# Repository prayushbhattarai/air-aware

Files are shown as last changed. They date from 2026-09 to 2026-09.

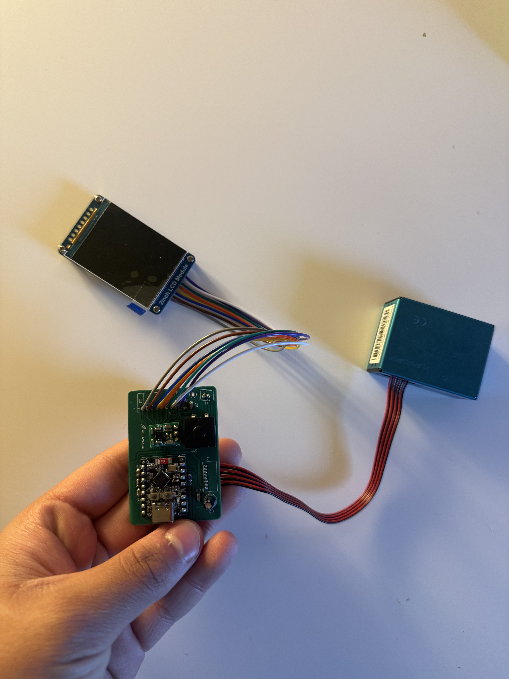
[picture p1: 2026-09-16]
media/assembled/assembled-pcb-whole.jpeg

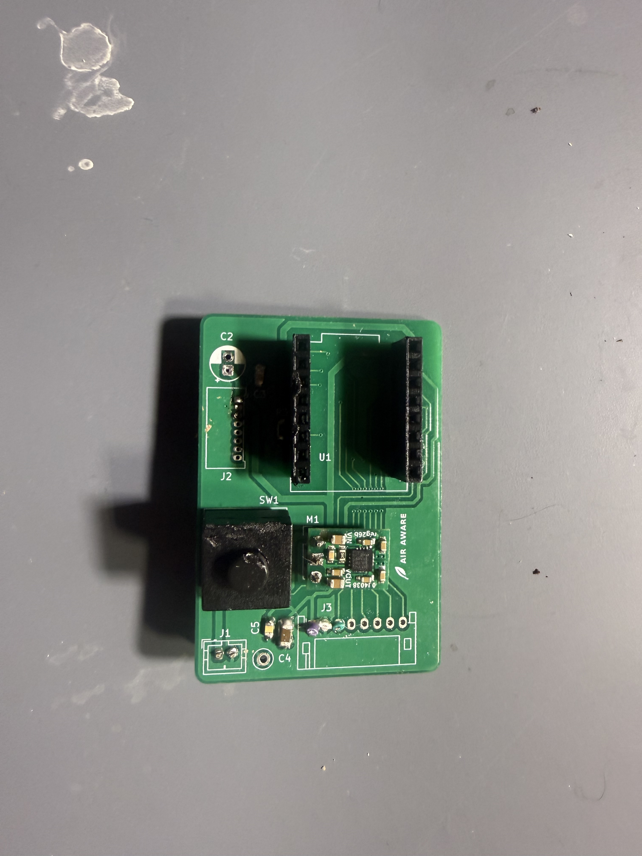
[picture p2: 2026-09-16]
media/process/solder-failure-top.jpeg

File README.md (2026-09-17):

# AirAware

AirAware is a portable particulate matter monitor designed to make air quality visible and understandable. The device measures airborne particles using a Plantower PMS5003 sensor and displays the results through a simple interface powered by an ESP32-C3.

The project combines PCB design, embedded programming, environmental sensing, and classroom education.

Project started: July 2026

## Overview

AirAware was built around a simple question:

What does the air around us actually contain?

Most people cannot see changes in particulate matter concentration as they happen. AirAware provides a portable way to measure those changes and display them in a format that is easy to understand.

The current device measures particulate matter and displays:

* Particle count
* PM2.5 concentration
* A visual air-quality indicator

The interface uses a simple facial indicator to help younger students interpret changes in particle concentration without needing to understand every measurement immediately.

## Hardware

The current AirAware device uses:

* ESP32-C3 SuperMini
* Plantower PMS5003 particulate matter sensor
* 2.0-inch 320 × 240 ST7789 display
* 3.7 V lithium-polymer battery
* Pololu S13V15F5 5 V boost regulator
* Custom 2-layer PCB

## How It Works

The PMS5003 pulls air through its sensing chamber and measures suspended particulate matter.

The sensor sends measurement data to the ESP32-C3 through UART.

The ESP32-C3 processes the sensor readings and updates the ST7789 display with the current particle measurements and visual indicator.

Basic data flow:

PMS5003
↓
UART communication
↓
ESP32-C3
↓
Data processing
↓
ST7789 display

## Display

The interface was designed to stay simple enough for classroom use.

The main screen emphasizes particle count while also showing PM2.5 concentration.

A facial indicator changes based on the measured particle level:

🙂 Lower particle concentration

😐 Moderate particle concentration

☹ Higher particle concentration

The device also includes a startup screen while the PMS5003 completes its initial warm-up period.

## Educational Use

AirAware was designed as both an engineering project and an educational tool.

Students use the devices in small groups to:

* Observe real-time particulate matter measurements
* Compare measurements from different environments
* Test how activities affect airborne particles
* Record experimental data
* Calculate averages
* Compare results between groups
* Discuss possible sources of particulate matter

The goal is to connect environmental science with measurements students collect themselves.

### firmware

Contains the code running on the ESP32-C3.

### hardware/kicad

Contains the editable KiCad project files:

* Schematic
* PCB layout
* KiCad project

### hardware/production

Contains files used to manufacture the PCB, including Gerber and drill files.

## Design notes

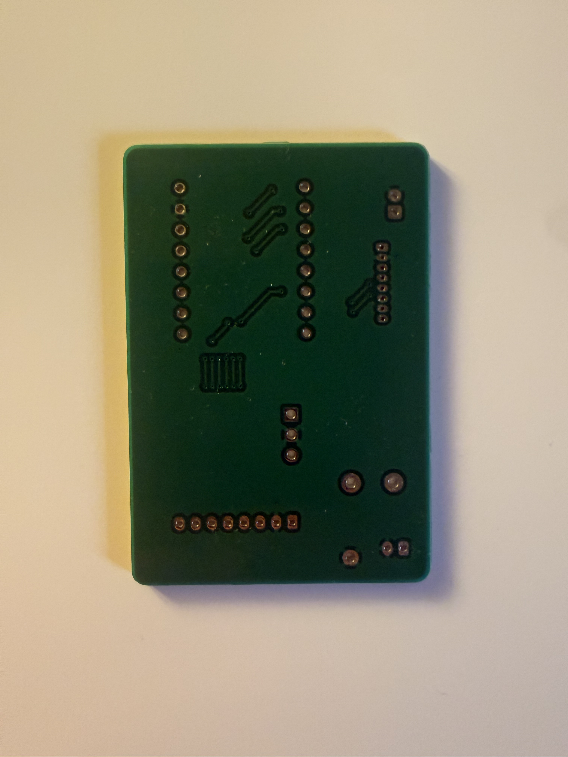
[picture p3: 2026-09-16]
media/pcb/pcb-back.jpeg

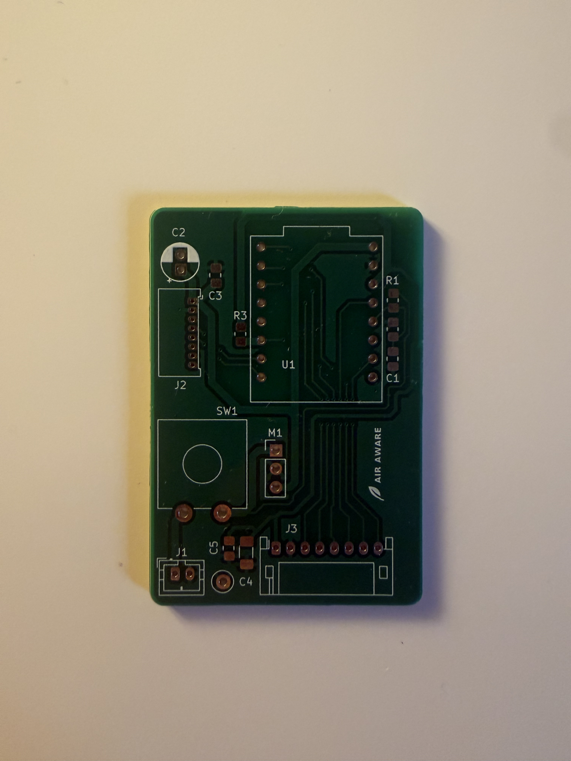
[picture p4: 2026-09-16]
media/pcb/pcb-front.jpeg

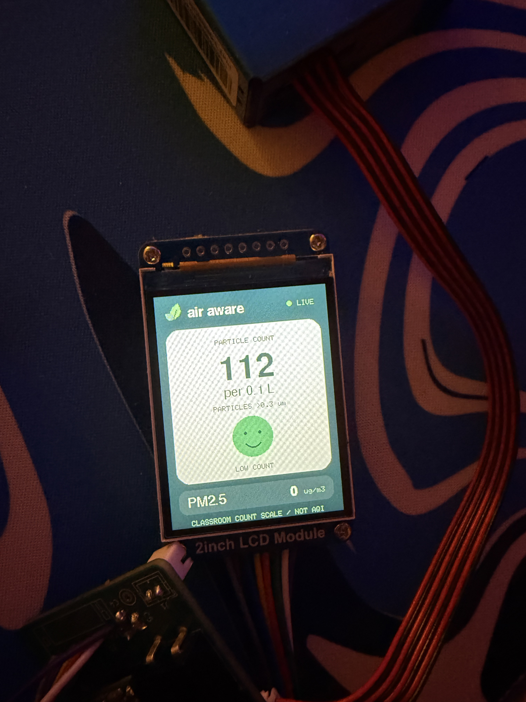
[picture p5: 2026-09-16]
media/interface/data-interface.jpeg

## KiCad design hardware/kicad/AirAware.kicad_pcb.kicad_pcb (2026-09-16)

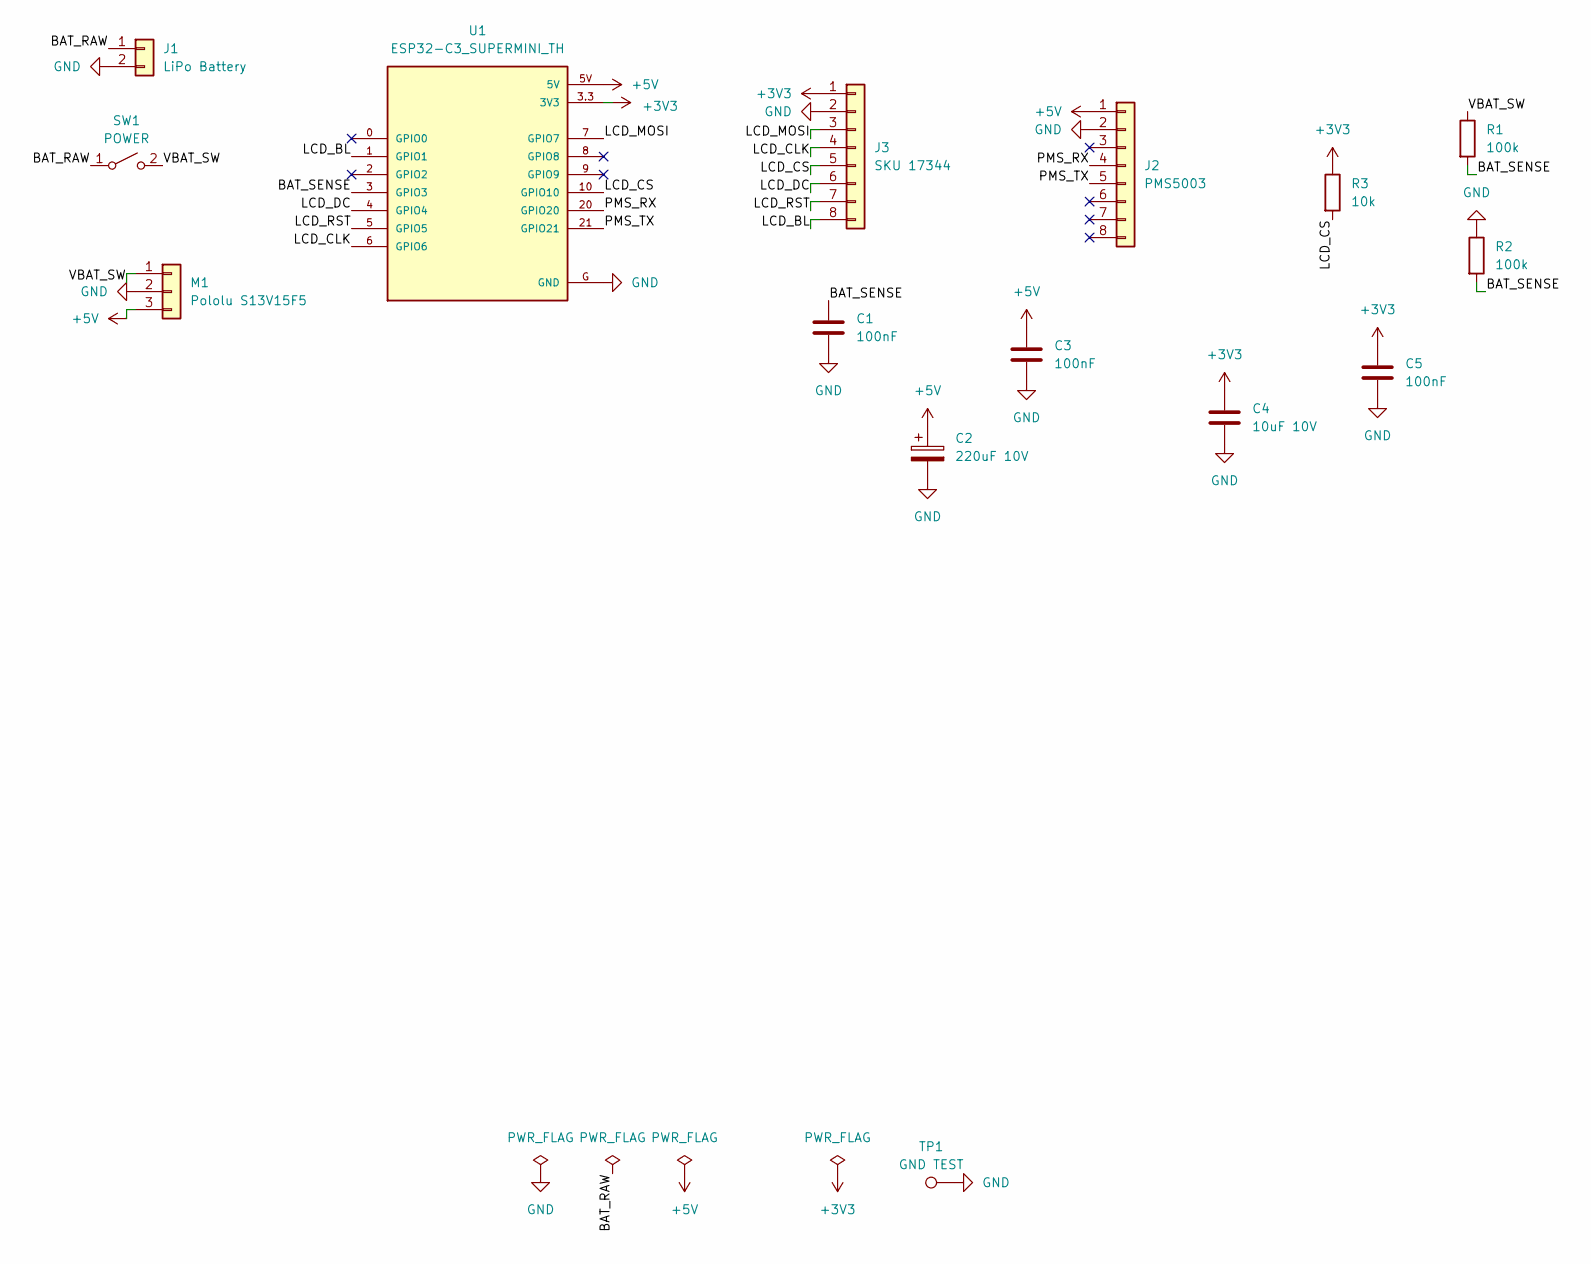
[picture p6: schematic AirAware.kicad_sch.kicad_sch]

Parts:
C1, C3, C5: 100nF; C_0805_2012Metric_Pad1.18x1.45mm_HandSolder
C2: 220uF 10V; CP_Radial_D5.0mm_P2.00mm
C4: 10uF 10V; C_1206_3216Metric_Pad1.33x1.80mm_HandSolder
J1: LiPo Battery; JST_PH_B2B-PH-K_1x02_P2.00mm_Vertical
J2: PMS5003; Molex_PicoBlade_53048-0810_1x08_P1.25mm_Horizontal
J3: SKU 17344; JST_PH_S8B-PH-K_1x08_P2.00mm_Horizontal
M1: Pololu S13V15F5; PinHeader_1x03_P2.54mm_Vertical
R1, R2: 100k; R_0805_2012Metric_Pad1.20x1.40mm_HandSolder
R3: 10k; R_0805_2012Metric_Pad1.20x1.40mm_HandSolder
SW1: POWER; SW_CW_GPTS203211B
TP1: GND TEST; TestPoint_Loop_D2.50mm_Drill1.0mm
U1: ESP32-C3_SUPERMINI_TH; MODULE_ESP32-C3_SUPERMINI_TH

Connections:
+3V3: C4.1, C5.1, J3.1, R3.1, U1.3.3 (3V3)
+5V: C2.1, C3.1, J2.1, M1.3, U1.5V
/BAT_RAW: J1.1, SW1.1 (A)
/BAT_SENSE: C1.1, R1.2, R2.2, U1.3 (GPIO3)
/LCD_BL: J3.8, U1.1 (GPIO1)
/LCD_CLK: J3.4, U1.6 (GPIO6)
/LCD_CS: J3.5, R3.2, U1.10 (GPIO10)
/LCD_DC: J3.6, U1.4 (GPIO4)
/LCD_MOSI: J3.3, U1.7 (GPIO7)
/LCD_RST: J3.7, U1.5 (GPIO5)
/PMS_RX: J2.4, U1.20 (GPIO20)
/PMS_TX: J2.5, U1.21 (GPIO21)
/VBAT_SW: M1.1, R1.1, SW1.2 (B)
GND: C1.2, C2.2, C3.2, C4.2, C5.2, J1.2, J2.2, J3.2, M1.2, R2.1, TP1.1, U1.G (GND)

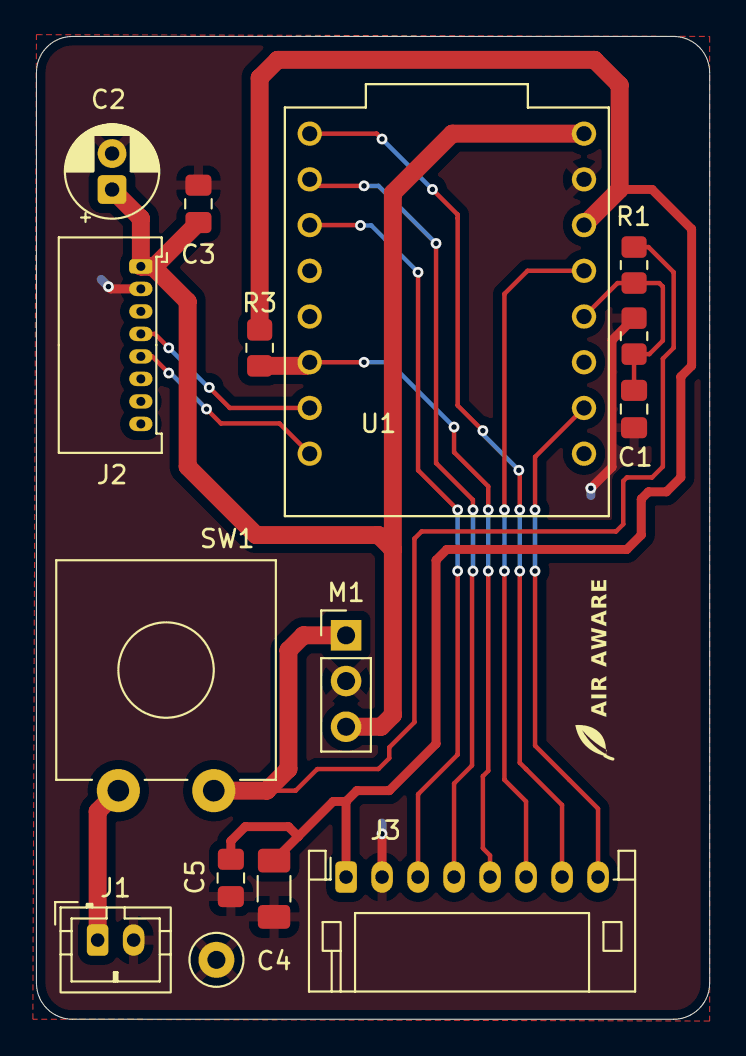
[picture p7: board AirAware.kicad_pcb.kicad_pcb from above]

Board: 2 copper layers, 37.4 x 54.6 mm, 16 parts (0 on the bottom side), 14 nets.

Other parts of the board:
H2: MountingHole; MountingHole_2.2mm_M2

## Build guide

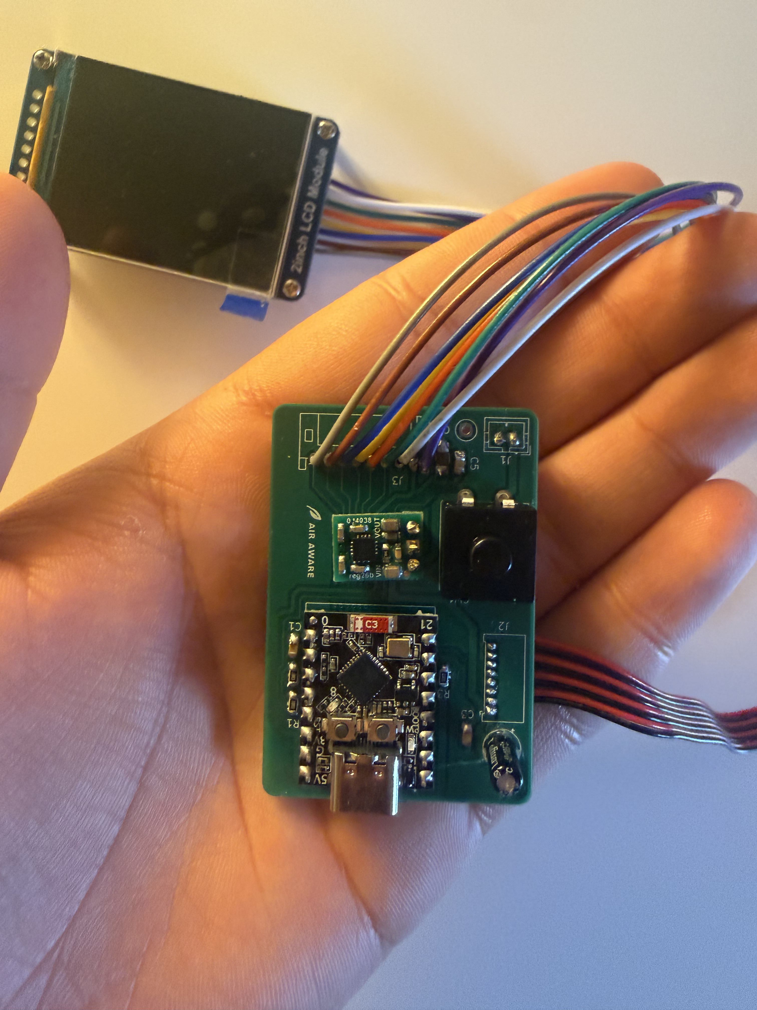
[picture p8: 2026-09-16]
media/assembled/assembled-pcb-front.jpeg

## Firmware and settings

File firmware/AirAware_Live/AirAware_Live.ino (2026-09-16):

// Air Aware Nature UI v4 PORTRAIT | ESP32-C3 SuperMini + ST7789 240x320 + PMS5003
// Libraries: Adafruit GFX Library; Adafruit ST7735 and ST7789 Library.
// Board: ESP32C3 Dev Module. USB CDC On Boot: Enabled.
// Working sensor connection: PMS TX -> GPIO21 (ESP receive).
// GPIO20 stays INPUT; this sketch never transmits to the sensor.
#include <Arduino.h>
#include <Adafruit_GFX.h>
#include <Adafruit_ST7789.h>
#include <SPI.h>
#include <Fonts/FreeSans9pt7b.h>
#include <Fonts/FreeSansBold9pt7b.h>
#include <Fonts/FreeSansBold24pt7b.h>
#include <math.h>
#include <string.h>
#include "driver/uart.h"
#include "driver/gpio.h"

constexpr int LCD_CS = 10, LCD_DC = 4, LCD_MOSI = 7;
constexpr int LCD_CLK = 6, LCD_RST = 5, LCD_BL = 1, PMS_RX = 21;
constexpr uint32_t WARMUP_MS = 30000UL, STALE_MS = 5000UL;
// Example CLASSROOM comparison bands, NOT health limits or AQI categories.
// Count is particles >0.3 micrometers per 0.1 liter, reported by the sensor.
constexpr uint16_t COUNT_YELLOW_AT = 300, COUNT_RED_AT = 1000;

Adafruit_ST7789 screen(&SPI, LCD_CS, LCD_DC, LCD_RST);
constexpr int SCREEN_W = 240, SCREEN_H = 320;
constexpr uint8_t DISPLAY_ROTATION = 0;
GFXcanvas16 canvas(SCREEN_W, SCREEN_H);
constexpr uint16_t rgb(uint8_t r, uint8_t g, uint8_t b) {
  return ((r & 248) << 8) | ((g & 252) << 3) | (b >> 3);
}
constexpr uint16_t BG = rgb(15, 40, 35), PANEL = rgb(29, 61, 51);
constexpr uint16_t PAPER = rgb(244, 244, 226), INK = rgb(25, 56, 45);
constexpr uint16_t MUTED = rgb(97, 119, 98), SAGE = rgb(167, 196, 162);
constexpr uint16_t MINT = rgb(179, 224, 160), GREEN = rgb(121, 204, 149);
constexpr uint16_t YELLOW = rgb(242, 202, 107), RED = rgb(235, 143, 124);
constexpr uint16_t GRAY = rgb(183, 192, 178);
constexpr float PI_F = 3.14159265f;

uint16_t pm25 = 0, particleCount03 = 0;
uint32_t lastReading = 0, wakeTime = 0, lastDraw = 0;
uint32_t rxBytes = 0, validFrames = 0;
bool haveReading = false;
uint8_t frame[32], used = 0;

uint16_t wordAt(int index) {
  return (uint16_t(frame[index]) << 8) | frame[index + 1];
}
void acceptByte(uint8_t value) {
  ++rxBytes;
  frame[used++] = value;
  if (used < sizeof(frame)) return;
  uint16_t sum = 0;
  for (int i = 0; i < 30; ++i) sum += frame[i];
  if (frame[0] == 0x42 && frame[1] == 0x4D && wordAt(2) == 28 &&
      sum == wordAt(30)) {
    pm25 = wordAt(12);             // Atmospheric PM2.5, ug/m3 (not CF=1)
    particleCount03 = wordAt(16);  // >0.3 um particles per 0.1 L
    lastReading = millis();
    haveReading = true;
    ++validFrames;
    used = 0;
  } else {
    memmove(frame, frame + 1, sizeof(frame) - 1);
    used = sizeof(frame) - 1;
  }
}
int countBand(uint16_t count) {
  return count >= COUNT_RED_AT ? 2 : (count >= COUNT_YELLOW_AT ? 1 : 0);
}
bool readingFresh(uint32_t now) {
  return haveReading && uint32_t(now - lastReading) < STALE_MS;
}
void textAt(const char *s, int x, int baseline, const GFXfont *font,
            uint16_t color) {
  canvas.setFont(font);
  canvas.setTextSize(1);
  canvas.setTextColor(color);
  canvas.setCursor(x, baseline);
  canvas.print(s);
}
void centered(const char *s, int x, int baseline, const GFXfont *font,
              uint16_t color) {
  canvas.setFont(font);
  canvas.setTextSize(1);
  int16_t bx, by;
  uint16_t w, h;
  canvas.getTextBounds(s, 0, baseline, &bx, &by, &w, &h);
  textAt(s, x - int(w) / 2 - bx, baseline, font, color);
}
void tiny(const char *s, int x, int y, uint16_t color) {
  textAt(s, x, y, nullptr, color);
}
void tinyCentered(const char *s, int x, int y, uint16_t color) {
  tiny(s, x - int(strlen(s)) * 3, y, color);
}

void leaf(int x, int y, float angle, float length, float width, uint16_t color) {
  const float dx = cosf(angle), dy = sinf(angle);
  int px = x, py = y, qx = x, qy = y;
  for (int i = 1; i <= 12; ++i) {
    const float t = i / 12.0f, spread = sinf(t * PI_F) * width;
    int ax = lroundf(x + dx * length * t - dy * spread);
    int ay = lroundf(y + dy * length * t + dx * spread);
    int bx = lroundf(x + dx * length * t + dy * spread);
    int by = lroundf(y + dy * length * t - dx * spread);
    canvas.fillTriangle(px, py, qx, qy, ax, ay, color);
    canvas.fillTriangle(qx, qy, ax, ay, bx, by, color);
    px = ax; py = ay; qx = bx; qy = by;
  }
}
void header(bool live) {
  canvas.fillScreen(BG);
  leaf(24, 32, -1.25f, 22, 6, MINT);
  leaf(25, 31, -2.6f, 13, 4, SAGE);
  canvas.drawLine(23, 35, 29, 19, BG);
  textAt("air aware", 44, 30, &FreeSansBold9pt7b, PAPER);
  if (live) {
    canvas.fillCircle(186, 23, 3, MINT);
    tiny("LIVE", 198, 20, SAGE);
  }
}
void drawFace(int band) {
  const int cx = 120, cy = 203;
  const uint16_t colors[] = {GREEN, YELLOW, RED, GRAY};
  canvas.fillCircle(cx, cy, 28, colors[band]);
  canvas.fillCircle(cx - 10, cy - 5, 2, INK);
  canvas.fillCircle(cx + 10, cy - 5, 2, INK);
  // Upturned corners = smile; straight = neutral; downturned = sad.
  for (int x = -10; x <= 10; ++x) {
    float bend = 5.0f * (1.0f - x * x / 100.0f);
    int y = cy + 10 + (band == 0 ? lroundf(bend) :
                       (band == 2 ? -lroundf(bend) : 0));
    canvas.fillCircle(cx + x, y, 1, INK);
  }
}
void drawWarmup(uint32_t elapsed) {
  header(false);
  // Subtle foliage behind the countdown.
  leaf(0, 242, -0.9f, 85, 20, PANEL);
  leaf(240, 198, 2.2f, 76, 19, PANEL);
  const int cx = 120, cy = 137, radius = 55;
  for (int d = 0; d < 360; d += 3) {
    float a = (d - 90) * PI_F / 180.0f;
    canvas.fillCircle(cx + lroundf(radius * cosf(a)),
                      cy + lroundf(radius * sinf(a)), 3, PANEL);
  }
  const int degrees = int((elapsed * 360UL) / WARMUP_MS);
  for (int d = 0; d <= degrees; d += 3) {
    float a = (d - 90) * PI_F / 180.0f;
    canvas.fillCircle(cx + lroundf(radius * cosf(a)),
                      cy + lroundf(radius * sinf(a)), 3, MINT);
  }
  const float tip = (degrees - 90) * PI_F / 180.0f;
  canvas.fillCircle(cx + lroundf(radius * cosf(tip)),
                    cy + lroundf(radius * sinf(tip)), 5, PAPER);
  char seconds[8];
  snprintf(seconds, sizeof(seconds), "%lu", (unsigned long)
           ((WARMUP_MS - elapsed + 999UL) / 1000UL));
  centered(seconds, cx, 148, &FreeSansBold24pt7b, PAPER);
  tinyCentered("SECONDS", cx, 162, SAGE);
  centered("A little time to settle", 120, 240, &FreeSansBold9pt7b, PAPER);
  tinyCentered("WAKING UP THE PARTICLE SENSOR", 120, 261, SAGE);
  canvas.fillRoundRect(93, 297, 54, 3, 1, PANEL);
  canvas.fillRoundRect(93, 297, 1 + int(elapsed * 53UL / WARMUP_MS), 3, 1, MINT);
}
void drawLive(uint32_t now) {
  const bool fresh = readingFresh(now);
  header(fresh);
  canvas.fillRoundRect(12, 48, 216, 212, 18, PAPER);
  tinyCentered("PARTICLE COUNT", 120, 66, MUTED);
  char value[8];
  if (fresh) snprintf(value, sizeof(value), "%u", unsigned(particleCount03));
  else strcpy(value, "--");
  centered(value, 120, 122, &FreeSansBold24pt7b, INK);
  centered("per 0.1 L", 120, 145, &FreeSans9pt7b, MUTED);
  tinyCentered("PARTICLES >0.3 um", 120, 158, MUTED);
  int band = fresh ? countBand(particleCount03) : 3;
  drawFace(band);
  const char *labels[] = {"LOW COUNT", "MID COUNT", "HIGH COUNT", "WAITING"};
  tinyCentered(labels[band], 120, 243, MUTED);
  canvas.fillRoundRect(12, 269, 216, 33, 11, PANEL);
  textAt("PM2.5", 24, 291, &FreeSans9pt7b, PAPER);
  if (fresh) snprintf(value, sizeof(value), "%u", unsigned(pm25));
  else strcpy(value, "--");
  canvas.setFont(&FreeSansBold9pt7b);
  int16_t bx, by; uint16_t w, h;
  canvas.getTextBounds(value, 0, 291, &bx, &by, &w, &h);
  textAt(value, 176 - int(w) - bx, 291, &FreeSansBold9pt7b, PAPER);
  tiny("ug/m3", 186, 284, SAGE);
  tinyCentered(fresh ? "CLASSROOM COUNT SCALE / NOT AQI" :
               (haveReading ? "SENSOR DATA LOST" : "WAITING FOR SENSOR DATA"),
               120, 311, SAGE);
}
void drawUI() {
  const uint32_t now = millis(), elapsed = now - wakeTime;
  if (elapsed < WARMUP_MS) drawWarmup(elapsed);
  else drawLive(now);
  screen.drawRGBBitmap(0, 0, canvas.getBuffer(), SCREEN_W, SCREEN_H);
}
void fatalError(const char *message) {
  screen.fillScreen(BG);
  screen.setFont(nullptr);
  screen.setTextSize(1);
  screen.setTextColor(PAPER);
  screen.setCursor(12, 30);
  screen.print(message);
  while (true) delay(1000);
}
void requireUart(esp_err_t result) {
  if (result != ESP_OK) fatalError(esp_err_to_name(result));
}
void startReceiver() {
  requireUart(gpio_reset_pin(GPIO_NUM_20));
  requireUart(gpio_reset_pin(GPIO_NUM_21));
  requireUart(gpio_set_direction(GPIO_NUM_20, GPIO_MODE_INPUT));
  requireUart(gpio_set_direction(GPIO_NUM_21, GPIO_MODE_INPUT));
  requireUart(gpio_set_pull_mode(GPIO_NUM_20, GPIO_PULLUP_ONLY));
  requireUart(gpio_set_pull_mode(GPIO_NUM_21, GPIO_PULLUP_ONLY));
  uart_config_t config = {};
  config.baud_rate = 9600;
  config.data_bits = UART_DATA_8_BITS;
  config.parity = UART_PARITY_DISABLE;
  config.stop_bits = UART_STOP_BITS_1;
  config.flow_ctrl = UART_HW_FLOWCTRL_DISABLE;
  config.source_clk = UART_SCLK_DEFAULT;
  requireUart(uart_param_config(UART_NUM_1, &config));
  requireUart(uart_driver_install(UART_NUM_1, 4096, 0, 0, nullptr, 0));
  requireUart(uart_set_pin(UART_NUM_1, UART_PIN_NO_CHANGE, PMS_RX,
                         UART_PIN_NO_CHANGE, UART_PIN_NO_CHANGE));
  requireUart(uart_flush_input(UART_NUM_1));
}
void setup() {
  gpio_reset_pin(GPIO_NUM_20);
  gpio_reset_pin(GPIO_NUM_21);
  gpio_set_direction(GPIO_NUM_20, GPIO_MODE_INPUT);
  gpio_set_direction(GPIO_NUM_21, GPIO_MODE_INPUT);
  pinMode(LCD_BL, OUTPUT);
  digitalWrite(LCD_BL, HIGH);
  delay(100);
  SPI.begin(LCD_CLK, -1, LCD_MOSI, LCD_CS);
  screen.init(240, 320, SPI_MODE0);
  screen.setRotation(DISPLAY_ROTATION);
  screen.setSPISpeed(10000000);
  screen.setTextWrap(false);
  canvas.setTextWrap(false);
  if (!canvas.getBuffer()) fatalError("Display buffer allocation failed");
  startReceiver();
  wakeTime = millis();
  drawUI();
  lastDraw = millis();
}
void loop() {
  // Continue receiving during warmup and animations; no 30-second delay().
  uint8_t data[256];
  const int count = uart_read_bytes(UART_NUM_1, data, sizeof(data), 0);
  for (int i = 0; i < count; ++i) acceptByte(data[i]);
  const uint32_t now = millis();
  const uint32_t interval = now - wakeTime < WARMUP_MS ? 200UL : 1000UL;
  if (now - lastDraw >= interval) {
    drawUI();
    lastDraw = now;
  }
  delay(1);
}

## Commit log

2026-09-16 Initial AirAware project
    Initial repository + hardware files
    [AirAware-B_Cu.gbr, AirAware-B_Mask.gbr, AirAware-B_Paste.gbr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]
2026-09-16 Fix AirAware firmware filename
    renamed AirAware_Live.ino.ino to just AirAware_Live.ino
    [AirAware_Live.ino]
2026-09-16 Add initial AirAware project photos
    Added the first set of photos documenting the PCB, interface development, soldering process, and device progress.
2026-09-17 Update README.md
    Updated readme to be more accurate to current version
